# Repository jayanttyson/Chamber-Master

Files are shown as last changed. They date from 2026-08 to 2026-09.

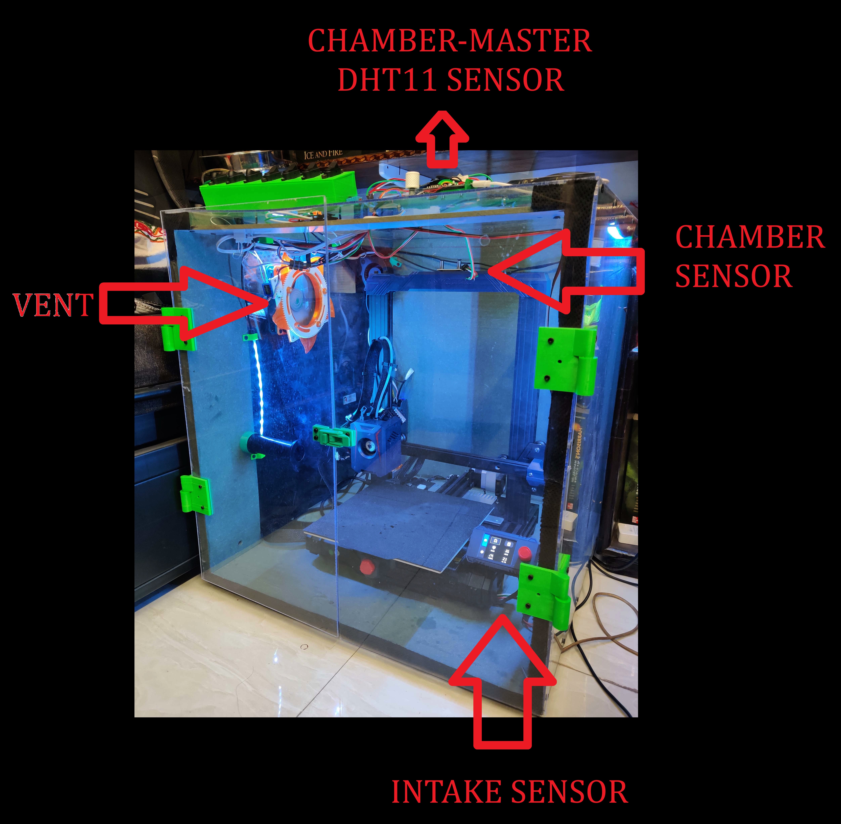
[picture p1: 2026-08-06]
Images/Setup.jpg

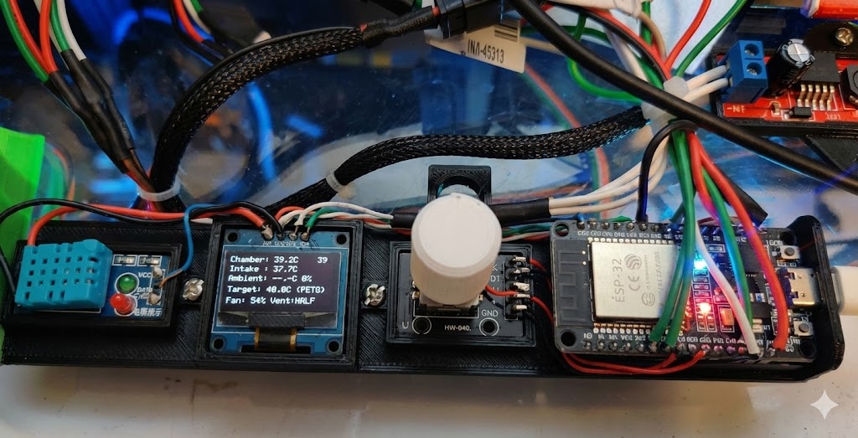
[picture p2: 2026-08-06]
Images/setup PCB.jpg

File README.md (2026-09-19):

<div align="center">

# **Chamber Master (v2.9-beta)**

**ESP32-based Smart 3D Printer Enclosure Controller**

Chamber Master Enclosure Setup

### 🎥 Watch the Video Demo
Watch the video (https://www.youtube.com/watch?v=ktXHP1pz5N8)

</div>

---

**Chamber Master** is an intelligent, ESP32-powered environmental controller for 3D printer enclosures. It features precise multi-zone temperature regulation, automated vent shutter control using directional hysteresis, dynamic 4-pin PC fan PWM control with low-side hard kill zero-RPM cut-off, adaptive material cooldown routines (for ABS/ASA thermal stress prevention), intake fault safety alerts, an OLED display UI, and a responsive Web Dashboard with mDNS support (`http://enclosure-monitor.local`).

---

## 🌟 Key Features

### 🌡️ Temperature Monitoring
temp
- **Chamber Temperature:** DS18B20 OneWire sensor placed inside the enclosure.
- **Intake Air Temperature:** Second DS18B20 placed on the printer's motherboard vent or fresh air intake path (essential for recirculation fault detection).
- **Ambient Environment:** DHT11 (or DHT22) for room temperature and relative humidity sensing.

### 🚪 Smart Vent Control
vent
- SG90 micro servo driving vent shutter with **three precise states**: Closed • Half-Open • Full-Open.
- Advanced **directional hysteresis logic** for rock-solid temperature stability (eliminates mechanical servo chatter and hunting).
- Servos perform an automated calibration cycle on boot for accurate homing.

### 💨 Fan Control & Hard Kill Transistor
- Standard 4-pin PC fan with 1 kHz PWM speed control and tachometer ISR feedback (real RPM displayed on OLED & web).
- Enforced **minimum 20% duty cycle (~51/255)** during active cooling and cooldown to prevent thermal shock.
- **2N2222 Low-Side Hard Kill Transistor:** Cuts the fan's Ground (GND) line on GPIO 15 when fan is OFF, overcoming the Intel 4-wire PC fan specification failsafe to achieve true 0 RPM.

### 🎯 Operating Modes
- **Material Presets:**
  - **PLA:** 30.0°C
  - **ASA:** 50.0°C
  - **ABS:** 60.0°C
  - **TPU:** 25.0°C
  - **PETG:** 40.0°C
- **Custom Mode:** User-selectable target (0.0°C to 120.0°C, 0.5°C step via encoder, debounced & saved persistently to NVS flash).
- **Adaptive Cooldown Mode:**
  - Starts at 20% fan speed + full vent open (vent opens before fan to avoid back-pressure noise).
  - Automatically adjusts fan speed to achieve ~1.5°C/min cooling rate.
  - Live progress bar + real-time countdown timer tick on OLED and Web Dashboard.

### 🛡️ Safety Features
- **Intake Fault Detection:** Triggers emergency max fan + full vent if intake air exceeds `Chamber Temp + 5.0°C` (prevents hot air recirculation into electronics).
- Automatic recovery banner clearing when fault condition resolves.

### 🖥️ User Interface (OLED & Encoder)
oled menu
- Crisp **SSD1306 128×64 OLED** display with blinking chamber temperature status.
- Intuitive **EC11 rotary encoder** with 50ms software debounced push button.
- **Double-Click** encoder button to safely exit active mode (closes vent, turns fan off).
- **QR Code Mode:** Generates pairing QR Code and text string for quick mobile access.

### 🌐 Responsive Web Dashboard
webpage gif
- Dark glassmorphic design with real-time 1-second background telemetry updates.
- Displays all sensor readings, fan speed/RPM, vent state, active mode & target temp.
- CSS animated spinning fan blades with dynamic RPM rotation speed.
- Cooldown progress ring + remaining time estimate.
- One-click **START COOLDOWN** remote button.
- Live printer camera iframe (`http://3d-print-live.local/`).
- Accessible on local network at **`http://enclosure-monitor.local`** (via mDNS).

---

## 📌 Hardware Pinout Diagram

| Hardware Module | ESP32 GPIO | Description |
| :--- | :--- | :--- |
| **SSD1306 OLED SDA** | GPIO 21 | I2C Data |
| **SSD1306 OLED SCL** | GPIO 22 | I2C Clock |
| **Chamber DS18B20** | GPIO 32 | OneWire Sensor Bus |
| **Intake DS18B20** | GPIO 13 | OneWire Sensor Bus |
| **Ambient DHT11** | GPIO 23 | Temperature & Humidity Data |
| **Fan PWM Signal** | GPIO 33 | 4-Pin Fan PWM Pin (1 kHz) |
| **Fan Tachometer** | GPIO 19 | Pulse ISR Input (Debounced) |
| **Hard Kill Transistor** | GPIO 15 | 2N2222 Base Pin (via 1kΩ Resistor) |
| **Vent Servo PWM** | GPIO 5 | SG90 Control Pulse |
| **Encoder CLK / DT / BTN**| GPIO 25 / 26 / 27 | Quadrature Encoder & Push Button |
| **Status LED** | GPIO 2 | High during active cooling/venting |

---

## 📁 Codebase Architecture

The project supports both single-file Arduino IDE workflows and PlatformIO multi-file modular builds:

- **Arduino IDE (Single-File / Tab Setup):**
  - **[`Chamber-Master.ino`](file:///c:/Users/JB/Documents/chamber%20master/Chamber-Master.ino):** Main standalone sketch containing full controller logic.
  - **[`config.h`](file:///c:/Users/JB/Documents/chamber%20master/config.h):** Separate tab for Wi-Fi credentials (`WIFI_SSID`, `WIFI_PASSWORD`, `MDNS_HOSTNAME`).

- **PlatformIO / VS Code (Modular Build):**
  - `include/`: Header declarations (`config.h`, `sensors.h`, `actuators.h`, `cooldown.h`, `ui_display.h`, `web_dashboard.h`).
  - `src/`: C++ module implementations (`main.cpp`, `config.cpp`, `sensors.cpp`, `actuators.cpp`, `cooldown.cpp`, `ui_display.cpp`, `web_dashboard.cpp`).

---

## 🖨️ Klipper Integration & Macros (v2.9-beta)

> *Hardware Tested & Verified: Klipper integration and macros proposed and verified on physical hardware by [Richard Kennett](https://github.com/richard-kennett) ([Issue #3](https://github.com/jayanttyson/Chamber-Master/issues/3#issuecomment-5619889047)).*

Chamber Master exposes a REST API endpoint (`/material`) allowing Klipper 3D printer firmware to automatically configure enclosure target temperatures and material profiles directly from filament start G-code or slicer profiles. Complete ready-to-use configuration files are located in the [`Klipper/`](Klipper/) directory.

### 1. Prerequisites on Klipper Host
Install mDNS resolution support on your Klipper host (Raspberry Pi / Linux):
```bash
sudo apt update && sudo apt install -y mdns avahi-daemon
```

### 2. Install Host Trigger Script
Copy [`Klipper/chamber_trigger.sh`](Klipper/chamber_trigger.sh) to your home directory (`$HOME`):
```bash
cp Klipper/chamber_trigger.sh ~/chamber_trigger.sh
chmod +x ~/chamber_trigger.sh
```
*Note: The script performs an IPv4 ping lookup (`ping -4 -c 1`) to cache and grab the controller's IP immediately, preventing curl DNS resolution timeouts in Klipper subshells.*

### 3. Klipper Macro Configuration
Add the tested macros below to your `printer.cfg` (or add `[include chamber_master.cfg]` using [`Klipper/chamber_master.cfg`](Klipper/chamber_master.cfg)):

```ini
[gcode_macro Chamber_Master]
description: Configuration variables for Chamber Master
variable_url: "enclosure-monitor.local"   # Matches mDNS hostname on OLED screen
gcode:

[gcode_shell_command chamber_curl]
command: bash $HOME/chamber_trigger.sh
timeout: 4.0
verbose: True

[gcode_macro SET_CHAMBER]
description: Set Chamber Master material mode and optional target temperature
gcode:
    {% set cf = printer.configfile.settings %}
    {% set url = cf['gcode_macro chamber_master'].variable_url %}

    # 1. Read material and force it to UPPERCASE
    {% set material = params.MATERIAL|default("XXX")|string|upper %}
    {% if material == "" %}
        {% set material = "XXX" %}
    {% endif %}

    # 2. Check if temperature was explicitly passed
    {% if 'TEMPERATURE' in params %}
        {% set temperature = params.TEMPERATURE|int %}
        RUN_SHELL_COMMAND CMD=chamber_curl PARAMS="{url} {material} {temperature}"
    {% else %}
        RUN_SHELL_COMMAND CMD=chamber_curl PARAMS="{url} {material}"
    {% endif %}

[gcode_macro START_CHAMBER_COOLDOWN]
description: Trigger Chamber Master adaptive cooldown routine
gcode:
    SET_CHAMBER MATERIAL=COOLDOWN
```

### 4. Slicer Filament Start G-Code Examples
In OrcaSlicer, PrusaSlicer, or Bambu Studio, add to your **Filament Start G-Code**:
```gcode
; Automate enclosure temperature for active filament
SET_CHAMBER MATERIAL=[filament_type]
```
For custom chamber temperatures:
```gcode
SET_CHAMBER MATERIAL=CUSTOM TEMPERATURE=55
```

### 5. Print End Cooldown
In your **Machine End G-Code** or `PRINT_END` macro:
```gcode
START_CHAMBER_COOLDOWN
```

---

## 🛠️ Setup & Installation

### Option A: Arduino IDE (Easiest)

1. **Add ESP32 Board Support:**
   - Go to **File → Preferences**
   - Add to *Additional Boards Manager URLs*: `https://raw.githubusercontent.com/espressif/arduino-esp32/gh-pages/package_esp32_index.json`
   - Go to **Tools → Board → Boards Manager**, search **esp32**, and click Install.

2. **Install Required Libraries (Tools → Manage Libraries):**
   - `Adafruit SSD1306`
   - `Adafruit GFX Library`
   - `OneWire`
   - `DallasTemperature`
   - `DHT sensor library` (by Adafruit)
   - `ESP32Encoder` (by Kevin Harrington)
   - `ESP32Servo` (by Kevin Harrington)
   - `QRCodeGFX` (by Ricmoo)

3. **Configure & Upload:**
   - Open [`Chamber-Master.ino`](file:///c:/Users/JB/Documents/chamber%20master/Chamber-Master.ino) in Arduino IDE.
   - Click the **`config.h`** tab at the top and set your Wi-Fi credentials:
     ```cpp
     #define WIFI_SSID     "YOUR_WIFI_NAME"
     #define WIFI_PASSWORD "YOUR_WIFI_PASSWORD"
     ```
   - Select Board **Tools → Board → ESP32 Dev Module**.
   - Connect your ESP32 and click **Upload**.

---

### Option B: PlatformIO (VS Code)

1. Open this workspace folder in VS Code with the PlatformIO extension installed.
2. Update Wi-Fi settings in `config.h`.
3. Connect your ESP32 via USB and run:
   ```bash
   pio run --target upload
   ```

---

## 💡 Pro Tips for Best Results

- **Intake Sensor Placement:** Place the intake DS18B20 directly at the fresh air entry point or near printer motherboard exhaust vents for early recirculation detection.
- **Fan Choice:** Choose a high-quality ≥2000 RPM 4-pin PWM fan (e.g., Noctua or Arctic) for silent yet effective airflow.
- **Vent Grease:** Apply a small amount of grease to gears and rotating flaps in the aperture vent mechanism for smooth operation.
- **Enclosure Material:** For ABS/ASA printing, pair with a well-sealed enclosure (IKEA Lack, Prusa enclosure, or custom build).

---

## 📄 License

MIT License. Free to use, modify, and distribute. Created by **Jayant Bhatia**.

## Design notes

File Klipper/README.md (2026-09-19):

# Chamber Master - Klipper Integration Guide

> **Hardware Tested & Verified**: Contributed by [Richard Kennett](https://github.com/richard-kennett) ([GitHub Issue #3](https://github.com/jayanttyson/Chamber-Master/issues/3#issuecomment-5619889047)).

This guide explains how to connect your **Chamber Master** enclosure controller to **Klipper 3D printer firmware**, allowing your slicer or filament profiles to automatically set enclosure modes and custom target temperatures, or trigger adaptive cooldown when a print finishes.

---

## Prerequisites

1. **mDNS Resolution on Klipper Host (Raspberry Pi / Linux):**
   Linux hosts often fail to resolve `.local` domains in subshells without mDNS packages installed. Run:
   ```bash
   sudo apt update
   sudo apt install -y mdns avahi-daemon
   ```

2. **Gcode Shell Command Extension:**
   Ensure `gcode_shell_command` is installed in Klipper (e.g. via **KIAUH** -> *Advanced* -> *G-Code Shell Command*).

---

## Installation Steps

### Step 1: Copy the Trigger Script
Copy [`chamber_trigger.sh`](chamber_trigger.sh) to your home directory (`$HOME`):
```bash
cp chamber_trigger.sh ~/chamber_trigger.sh
chmod +x ~/chamber_trigger.sh
```

> **Why this script is needed:**
> Linux curl subshells can hang or fail resolving `.local` mDNS domains. The script performs a fast IPv4 ping lookup (`ping -4 -c 1 enclosure-monitor.local`) to grab the IP address directly from the network cache before issuing the HTTP request to Chamber Master.

### Step 2: Include Configuration in Klipper
Copy [`chamber_master.cfg`](chamber_master.cfg) to your Klipper config directory (usually `~/printer_data/config/`):
```bash
cp chamber_master.cfg ~/printer_data/config/
```

Add the following line to your `printer.cfg`:
```ini
[include chamber_master.cfg]
```

Or copy the macros from [`chamber_master.cfg`](chamber_master.cfg) directly into your `printer.cfg`.

Restart Klipper (`FIRMWARE_RESTART`).

---

## Macros Reference

| Macro | Parameters | Example | Description |
| :--- | :--- | :--- | :--- |
| `SET_CHAMBER` | `MATERIAL` *(string)*, `TEMPERATURE` *(int/float, optional)* | `SET_CHAMBER MATERIAL=ABS` | Sets enclosure preset mode (`PLA`, `ASA`, `ABS`, `TPU`, `PETG`) |
| `SET_CHAMBER` | `MATERIAL=CUSTOM`, `TEMPERATURE=<target>` | `SET_CHAMBER MATERIAL=CUSTOM TEMPERATURE=55` | Sets custom target enclosure temperature |
| `SET_CHAMBER` | `MATERIAL=COOLDOWN` | `SET_CHAMBER MATERIAL=COOLDOWN` | Initiates active adaptive cooldown routine |
| `START_CHAMBER_COOLDOWN` | *(none)* | `START_CHAMBER_COOLDOWN` | Convenience alias for cooldown |

---

## Slicer Configuration

### Filament Start G-Code
In OrcaSlicer, PrusaSlicer, or Bambu Studio, add to your **Filament Start G-Code**:
```gcode
; Set Chamber Master mode based on active filament
SET_CHAMBER MATERIAL=[filament_type]
```
For filaments requiring a specific custom temperature:
```gcode
SET_CHAMBER MATERIAL=CUSTOM TEMPERATURE=55
```

### Machine End G-Code
In your slicer's **Machine End G-Code** or `PRINT_END` macro:
```gcode
; Start adaptive enclosure cooldown routine
START_CHAMBER_COOLDOWN
```

---

## Testing & Verification

You can test the trigger script directly in your terminal:
```bash
# Test material preset
bash ~/chamber_trigger.sh enclosure-monitor.local PETG

# Test custom temperature
bash ~/chamber_trigger.sh enclosure-monitor.local CUSTOM 60

# Test cooldown trigger
bash ~/chamber_trigger.sh enclosure-monitor.local COOLDOWN
```

Or from the Klipper console in Mainsail / Fluidd:
```gcode
SET_CHAMBER MATERIAL=PLA
SET_CHAMBER MATERIAL=CUSTOM TEMPERATURE=45
START_CHAMBER_COOLDOWN
```

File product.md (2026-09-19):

# Product Requirement & Specification Document (product.md)

## Project Overview
**Product Name:** Chamber Master (3D Printer Enclosure Controller)  
**Version:** 2.9-beta (Klipper Integration)  
**Author:** Jayant Bhatia  
**License:** MIT License  

The **3D Printer Enclosure Controller** is an intelligent, embedded ESP32 system designed for monitoring and controlling environmental conditions within a 3D printer enclosure. It provides real-time thermal monitoring across multiple zones, automated servo-driven ventilation control, dynamic 4-pin PC fan PWM management with low-side hard kill zero-RPM control, adaptive material cooldown routines (ABS/ASA thermal stress prevention), intake fault safety protection, rotary encoder UI with OLED display, a modern responsive web dashboard accessible via mDNS (`http://enclosure-monitor.local`), and native REST API integration with Klipper 3D printer firmware.

---

## Codebase Architecture (v2.5 Modular Structure)

The codebase supports **both** a clean multi-module architecture (PlatformIO / VS Code) and a single-file legacy format (`Chamber-Master.ino`):

```
chamber master/
├── Chamber-Master.ino      # Main standalone sketch (Arduino IDE)
├── config.h                # WiFi SSID, Password & Hostname configuration tab
├── README.md               # Hardware pinouts & setup guide
└── product.md              # Specification document
```

---

## Hardware Specifications & Pinout Mapping

| Component | Interface / Type | ESP32 GPIO Pin | Notes |
| :--- | :--- | :--- | :--- |
| **SSD1306 OLED (128x64)** | I2C (Address 0x3C) | SDA: GPIO 21, SCL: GPIO 22 | Main UI Display |
| **Chamber Temp Sensor** | DS18B20 (OneWire) | GPIO 32 | Internal enclosure temperature |
| **Intake Temp Sensor** | DS18B20 (OneWire) | GPIO 13 | Air intake temperature |
| **Ambient Temp & Humidity** | DHT11 | GPIO 23 | External ambient environment |
| **Fan PWM Control** | 4-Pin PWM Fan | GPIO 33 | 1 kHz, 8-bit resolution |
| **Fan Tachometer Input** | Pulse Frequency ISR | GPIO 19 | Measures fan RPM |
| **Fan Hard Kill Transistor** | 2N2222 Low-side switch | GPIO 15 | True 0 RPM ground cut-off (overrides CPU fan failsafe) |
| **Vent Servo Control** | SG90 / Continuous Servo | GPIO 5 | Microsecond pulse control |
| **Rotary Encoder CLK** | EC11 Encoder | GPIO 25 | Quadrature decoder |
| **Rotary Encoder DT** | EC11 Encoder | GPIO 26 | Quadrature decoder |
| **Rotary Encoder Button** | Push Button | GPIO 27 | Active LOW with internal pullup |
| **Status LED Indicator** | Onboard/External LED | GPIO 2 | High when fan & vent active |

---

## Operating Modes

1. **PLA Mode:** Target Chamber Temp = 30.0°C (Prevents heat creep & nozzle clogs).
2. **ASA Mode:** Target Chamber Temp = 50.0°C (Maintains chamber warmth for warping prevention).
3. **ABS Mode:** Target Chamber Temp = 60.0°C (High ambient heat retention for structural integrity).
4. **TPU Mode:** Target Chamber Temp = 25.0°C (Maximum active cooling for flexible filament).
5. **PETG Mode:** Target Chamber Temp = 40.0°C (Balanced thermal environment).
6. **CUSTOM Mode:** User selectable target (0.0°C to 120.0°C, 0.5°C step via encoder saved to NVS).
7. **COOLDOWN Mode:** Adaptive cooling routine. Starts at 20% fan duty (~51/255) to prevent thermal shock, adjusts fan duty dynamically based on temperature drop rate (°C/min), and closes vent upon completion. Progress tracked from original start temperature (v2.5 fix).
8. **QR CODE Mode:** Displays QR Code and URL string (`http://enclosure-monitor.local`) for quick mobile dashboard pairing.

---

## v2.5 Production Fixes

| # | Category | Fix |
| :--- | :--- | :--- |
| 1 | **Bug** | Cooldown progress bar now tracks from original start temp, not rolling 60s window |
| 2 | **Bug** | EC11 encoder button 50ms debounce eliminates phantom double-clicks |
| 3 | **Bug** | Button handler uses isolated timestamp (`btnNow`) preventing mid-loop timing drift |
| 4 | **Bug** | Cooldown start guards against NaN chamber temp (falls back to 60°C) |
| 5 | **Improvement** | NVS flash writes debounced to 2s idle on custom target encoder scrolling |
| 6 | **Improvement** | WiFi hostname changed from `"ENCLOSURE MONITOR"` to `"enclosure-monitor"` (RFC 952) |
| 7 | **Improvement** | `/status` endpoint includes `Access-Control-Allow-Origin: *` CORS header |
| 8 | **Improvement** | Unknown web routes return proper 404 via `server.onNotFound()` |
| 9 | **Improvement** | Vent opens before fan engages in cooldown to prevent back-pressure noise |
| 10 | **Cleanup** | Removed unnecessary `(int)` cast on `ambientHum` assignment (`roundf()` instead) |
| 11 | **Feature (v2.9-beta)** | REST API `/material` endpoint for Klipper 3D printer firmware & slicer integration (contributed / proposed by [@richard-kennett](https://github.com/richard-kennett)) |

---

## Hardware Rationale: 4-Pin CPU Fan Failsafe & Hard Kill Transistor

Standard 4-pin PC cooling fans adhere to the **Intel 4-Wire PWM Fan Specification**. As a hardware CPU protection feature:
- Many PC fans treat a **0% PWM signal** or disconnected PWM wire as an emergency state, keeping the fan spinning at a **minimum fallback speed (~20% RPM, ~500–800 RPM)** so a CPU does not overheat if the PWM controller fails.
- Therefore, driving 0% duty on GPIO 33 alone fails to turn off the fan on hardware-failsafe PC fans.
- The **2N2222 low-side transistor** circuit on GPIO 15 physically cuts the fan's Ground (GND) rail when `FAN_OFF` is commanded, guaranteeing **true 0 RPM operation** and eliminating lingering motor hum/spin.

---

## Control Logic & State Management

### 1. Vent Servo Control
- **Closed:** Continuous pulse = 2000 µs (SERVO_FORWARD_PULSE).
- **Open:** Continuous pulse = 1000 µs (SERVO_REVERSE_PULSE).
- **Stop:** Pulse = 1500 µs (SERVO_STOP_PULSE).
- **Hysteresis Logic:**
  - `Temp > Target + 2.0°C`: Full Open Vent + FAN_HIGH (100% duty).
  - `Temp > Target - 1.0°C`: Half Open Vent + FAN_LOW (55% duty).
  - `Temp < Target - 2.0°C`: Close Vent + FAN_OFF (0% duty, Hard Kill active).

### 2. Fan & Hard Kill Transistor Operation
- **FAN_OFF / 0 Duty:** GPIO 15 goes `LOW`, turning off the 2N2222 transistor to disconnect the fan GND rail. `fanPWM.writeScaled(0.0f)` sets PWM to 0.
- **FAN_LOW / FAN_HIGH / Active Cooldown:** GPIO 15 goes `HIGH`, connecting fan GND rail. PWM duty cycle regulates fan speed.

### 3. Intake Fault Protection
- If `Intake Temp > Chamber Temp + 5.0°C`, system triggers `INTAKE FAULT`.
- Vent immediately opens fully, fan runs at `FAN_HIGH` (100%), OLED shows `INTAKE FAULT!`, and Web Dashboard displays a blinking alert banner.
- Clears automatically when `Intake Temp <= Chamber Temp + 2.0°C`.

---

## Web Dashboard & REST API Specs

- **GET `/`**: Responsive HTML/CSS Web Dashboard with glassmorphism design, real-time stat cards, spinning fan SVG animation, circular cooldown progress gauge, live camera iframe embed (`http://3d-print-live.local/`), and start cooldown button.
- **GET `/status`**: Returns JSON object:
  ```json
  {
    "chamberTemp": 42.5,
    "intakeTemp": 31.0,
    "ambientTemp": 24.2,
    "ambientHum": 45,
    "fanRpm": 2100,
    "fanDuty": 55,
    "activeMode": "ABS",
    "targetTemp": "60.0",
    "ventState": "HALF OPEN",
    "fault": "NONE",
    "estSeconds": -1,
    "progress": 0.0
  }
  ```
- **POST `/start_cooldown`**: Initiates adaptive cooldown mode from web interface.
- **GET / POST `/material`**: Sets active material preset mode or custom temperature from Klipper / slicer macros.
  - **Parameters:**
    - `material` *(string, required)*: Material mode name (`PLA`, `ASA`, `ABS`, `TPU`, `PETG`, `CUSTOM`, `COOLDOWN`). Case-insensitive.
    - `temperature` or `temp` *(float, optional)*: Target chamber temperature in °C (0.0 to 120.0). Applied and saved to NVS when `material=CUSTOM`.
  - **Success Response (200 OK):**
    ```json
    {
      "status": "OK",
      "mode": "PLA",
      "targetTemp": 30.0
    }
    ```
  - **Error Response (400 Bad Request):**
    ```json
    {
      "error": "Missing 'material' parameter"
    }
    ```

---

## Klipper Integration Architecture (v2.9-beta)

> **Physical Hardware Validation:** Verified and contributed by [Richard Kennett](https://github.com/richard-kennett) ([Issue #3](https://github.com/jayanttyson/Chamber-Master/issues/3#issuecomment-5619889047)).

1. **Host Prerequisites:**
   - Linux Klipper host requires mDNS name resolution installed (`sudo apt install -y mdns avahi-daemon`).
2. **Fast IPv4 Resolution Script (`chamber_trigger.sh`):**
   - Resolves `enclosure-monitor.local` via `ping -4 -c 1 ${URL}` to populate and read the local IP directly, preventing curl DNS resolution timeouts in Klipper subshells.
   - Dispatches curl call to `/material` endpoint with material and optional temperature parameters.
3. **Klipper Macros (`chamber_master.cfg`):**
   - `[gcode_macro Chamber_Master]`: Stores `variable_url: "enclosure-monitor.local"`.
   - `[gcode_shell_command chamber_curl]`: Invokes `bash $HOME/chamber_trigger.sh` with a 4.0s timeout.
   - `[gcode_macro SET_CHAMBER]`: Normalizes material to uppercase and passes target temperature if specified.
   - `[gcode_macro START_CHAMBER_COOLDOWN]`: Dispatches `SET_CHAMBER MATERIAL=COOLDOWN` for automated post-print cooling.

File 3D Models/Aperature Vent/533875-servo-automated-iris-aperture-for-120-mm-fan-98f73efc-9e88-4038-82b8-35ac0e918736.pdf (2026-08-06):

## Summary

Remix for fitting the iris mechanism directly to 120 mm fan.

3D Printers (https://printables.com/model?categoryId=1) > 3D Printers - Upgrades (https://printables.com/model?categoryId=2)

This is a remix from https://www.printables.com/model/5122-servoautomated-iris-aperture-for-air-flow-control (https://www.printables.com/model/5122-servo-automated-iris-aperture-for-air-flow-control)
Many thanks to @AcEKrystal

I've changed the base plate only, to mount it directly to 120 mm fan. Servo motor is moved to allow 4 screws for tightening to the fan.

Only “baseplate-aperature-120mm-fan” file was modified, rest of the files are original, but I've included them here to have complete set of files to make this project.

Design has two things improved that are not visible on the pictures:
1. Servo 3 mm screw hole is moved slightly because it was at an angle
2. Right side of the servo mounting plate is extended so that the blade is not catching on the edge, but rather is gliding on the mount itself.

## This remix is based on

M (https://printables.com/@MichalCiombor_108701) MichalCiombor (https://printables.com/@MichalCiombor_108701)

## Servo automated iris / aperture for 120 mm fan

VIEW IN BROWSER (https://printables.com/model/533875-servo-automated-iris-aperture-for-120-mm-fan)

updated 23. 7. 2023 | published 23. 7. 2023

3D MODEL ONLY

## Model files

Servo automated iris / aperture for air flow controll (https://printables.com/model/5122-servo-automated-iris-aperture-for-air-flow-control)

by AcE Krystal (https://printables.com/@AcEKrystal)

## License

This work is licensed under a
Creative Commons (4.0 International License)

Attribution-ShareAlike (http://creativecommons.org/licenses/by-sa/4.0/)

✖ | Sharing without ATTRIBUTION
✔ | Remix Culture allowed
✔ | Commercial Use
✔ | Free Cultural Works
✔ | Meets Open Definition

baseplate-aperature-120mm-fan.stl

door_blade_final.stl

spur-gear-12th-125mo-145at.stl

spur-gear-107th-125mo-145at.stl

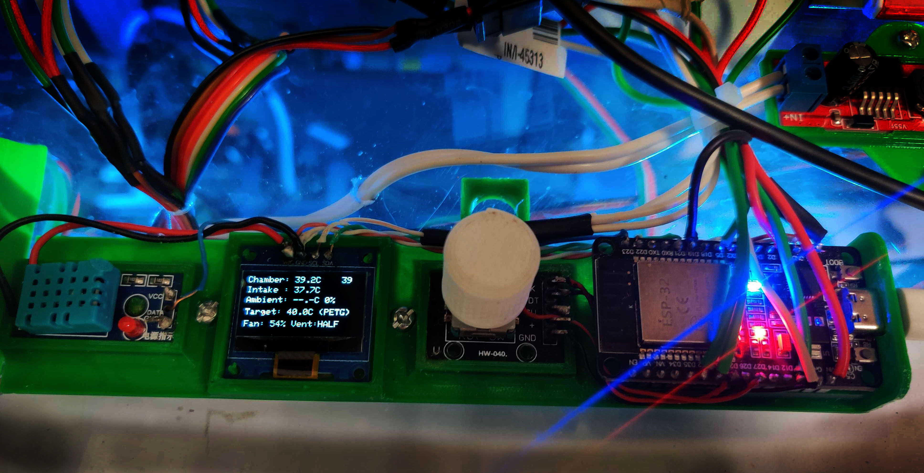
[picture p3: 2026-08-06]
Images/chamber master.jpg

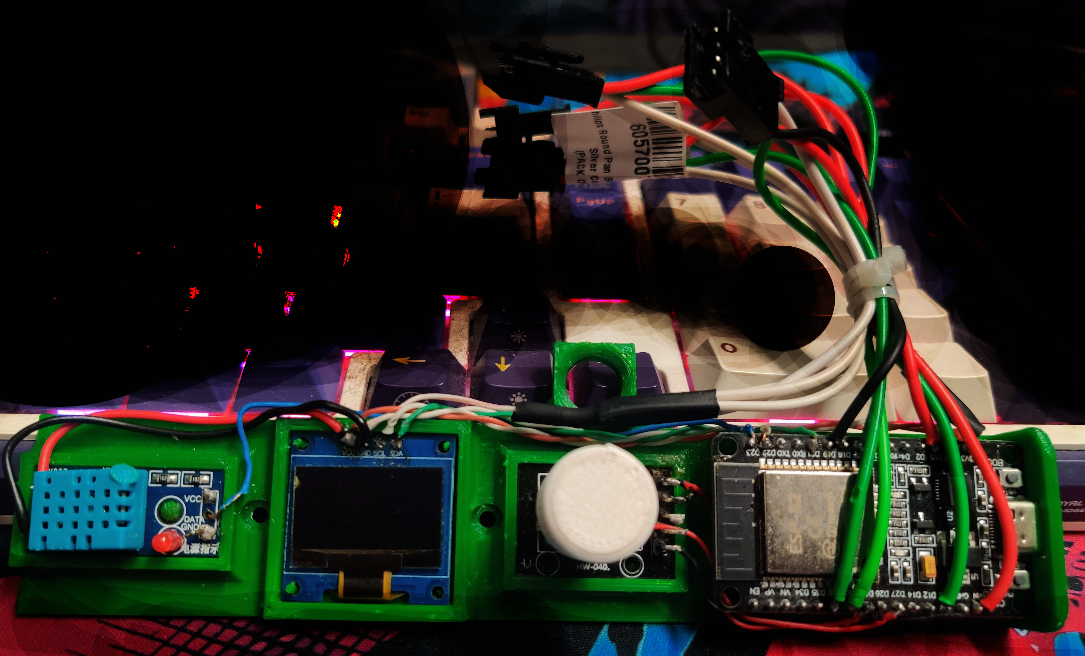
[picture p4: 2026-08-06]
Images/pcb off.jpg

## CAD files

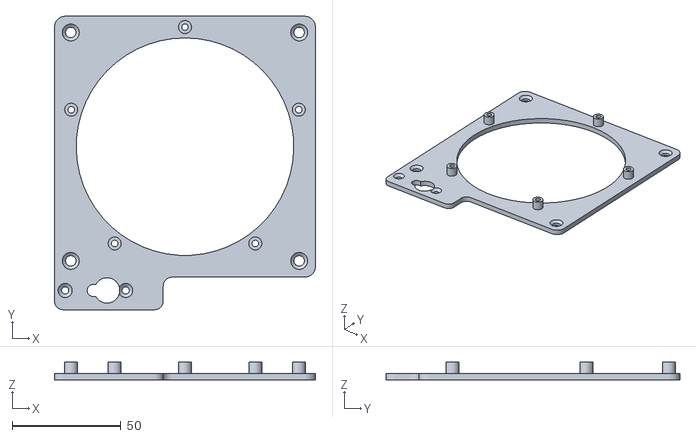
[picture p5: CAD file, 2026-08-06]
3D Models/Aperature Vent/baseplate-aperature-120mm-fan.stl
120.0 x 135.0 x 8.20

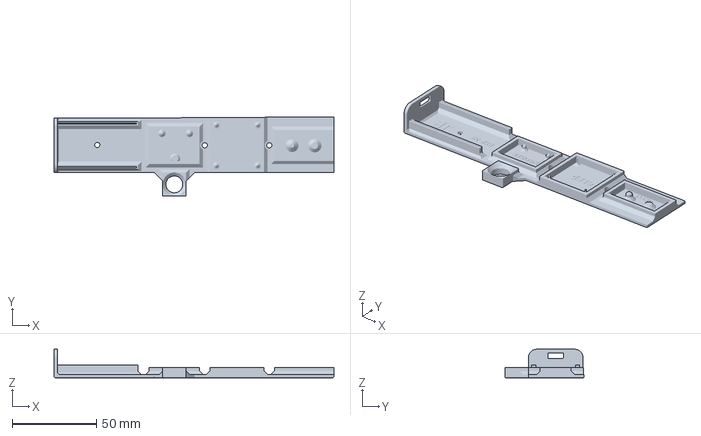
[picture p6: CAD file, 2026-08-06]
3D Models/Chamber-Master mount/pcb mounts_1.3mf
166.6 x 47.2 x 17.0 mm

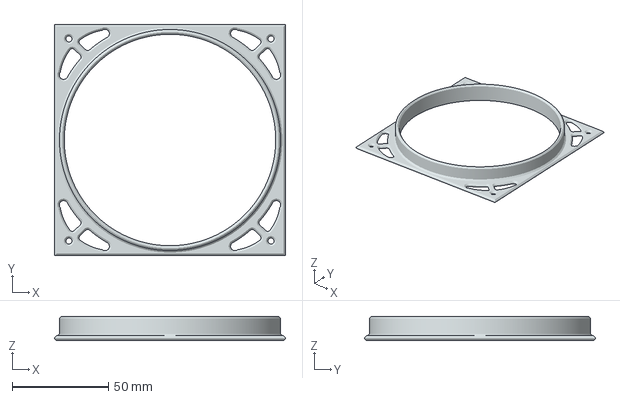
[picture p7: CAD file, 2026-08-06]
3D Models/MISC/fan bracket male.3mf
120.0 x 120.0 x 12.5 mm

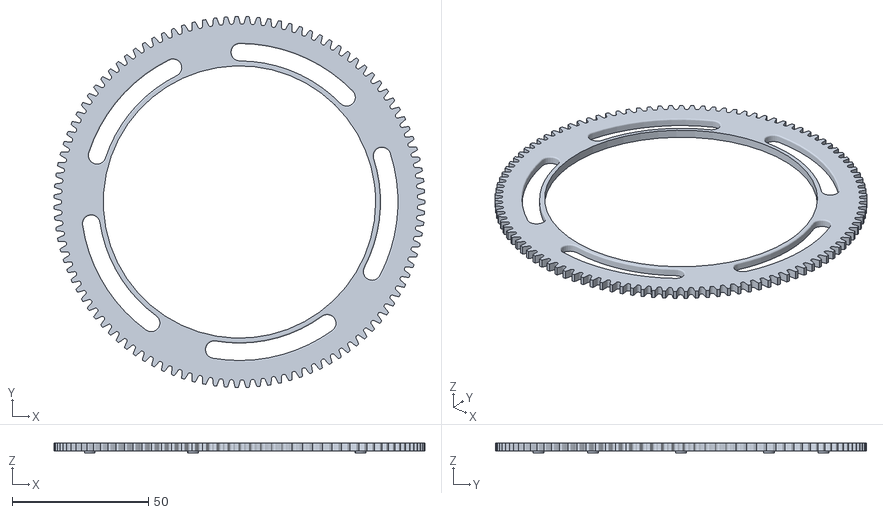
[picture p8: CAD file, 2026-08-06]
3D Models/Aperature Vent/spur-gear-107th-125mo-145at.stl
136.2 x 136.2 x 3.80

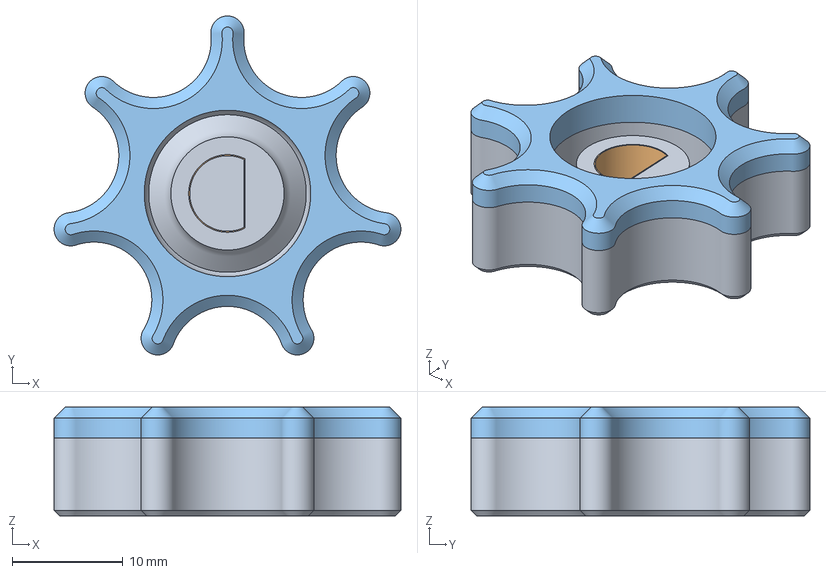
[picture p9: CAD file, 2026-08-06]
3D Models/MISC/Dshaft 6mm knob.3mf
31.3 x 30.6 x 9.80 mm

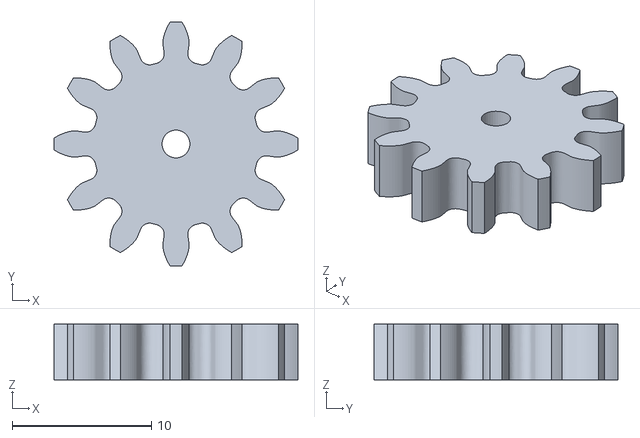
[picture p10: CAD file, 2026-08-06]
3D Models/Aperature Vent/spur-gear-12th-125mo-145at.stl
17.5 x 17.5 x 4.00

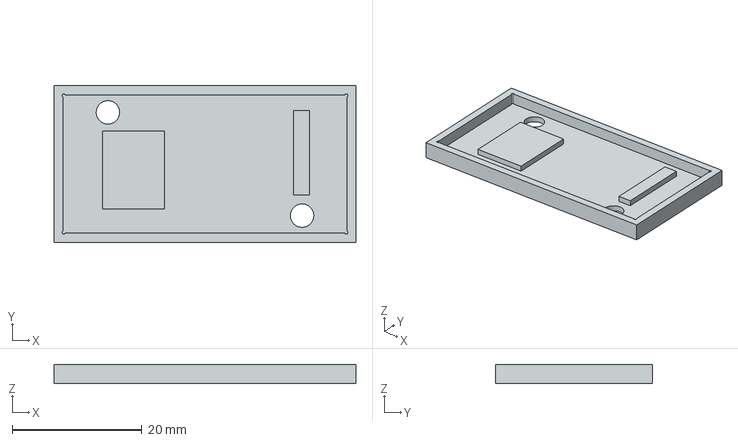
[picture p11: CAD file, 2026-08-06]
3D Models/MISC/XM4015E1.3mf
46.5 x 24.1 x 3.00 mm

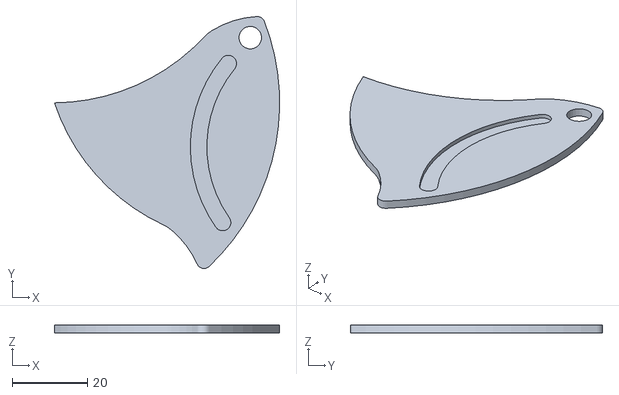
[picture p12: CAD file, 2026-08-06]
3D Models/Aperature Vent/door_blade_final.stl
60.0 x 67.1 x 2.00

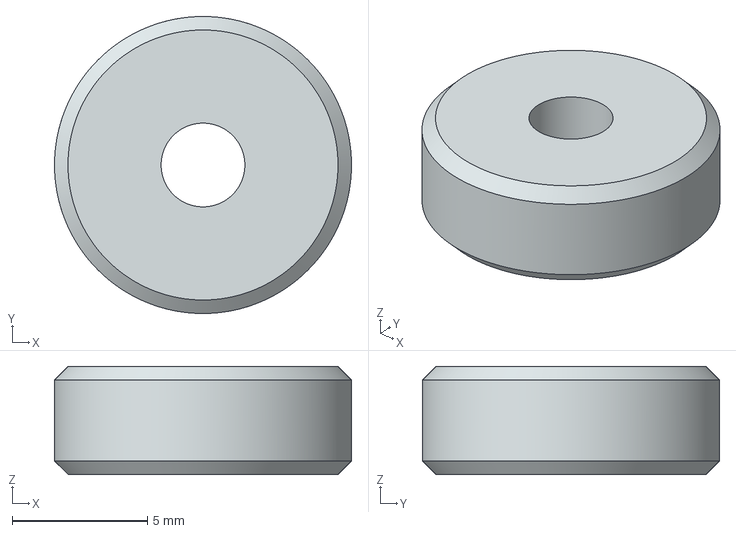
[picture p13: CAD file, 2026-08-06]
3D Models/MISC/simple 3mm screw washer_2.3mf
11.0 x 11.0 x 4.00 mm

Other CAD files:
3D Models/Chamber-Master mount/chambertemp mount.prt
3D Models/Chamber-Master mount/pcb mounts.prt
3D Models/MISC/Dshaft 6mm knob.prt
3D Models/MISC/XM4015E1 footprint.prt
3D Models/MISC/esp 32 usb C 30 pin Footprint.prt
3D Models/MISC/fan bracket male.prt

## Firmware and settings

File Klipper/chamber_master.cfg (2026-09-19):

# ==============================================================================
# Chamber Master - Klipper Configuration & Macros
# Tested and contributed by Richard Kennett (https://github.com/richard-kennett - Issue #3)
#
# Requirements:
#   1. gcode_shell_command extension enabled in Klipper (installed via KIAUH)
#   2. chamber_trigger.sh placed at $HOME/chamber_trigger.sh:
#        cp Klipper/chamber_trigger.sh ~/chamber_trigger.sh
#        chmod +x ~/chamber_trigger.sh
#   3. mDNS resolution package on Klipper host:
#        sudo apt update && sudo apt install -y mdns
#
# Installation:
#   Include this file in your printer.cfg:
#     [include chamber_master.cfg]
# ==============================================================================

[gcode_macro Chamber_Master]
description: Configuration variables for Chamber Master
variable_url: "enclosure-monitor.local"   # Matches hostname on OLED screen
gcode:
    # Configuration storage macro

[gcode_shell_command chamber_curl]
command: bash $HOME/chamber_trigger.sh
timeout: 4.0
verbose: True

[gcode_macro SET_CHAMBER]
description: Set Chamber Master material mode (PLA, ASA, ABS, TPU, PETG, CUSTOM, COOLDOWN) and optional target temperature
gcode:
    {% set cf = printer.configfile.settings %}
    {% set url = cf['gcode_macro chamber_master'].variable_url %}

    # 1. Read material and force to UPPERCASE
    {% set material = params.MATERIAL|default("XXX")|string|upper %}
    {% if material == "" %}
        {% set material = "XXX" %}
    {% endif %}

    # 2. Check if temperature was explicitly passed
    {% if 'TEMPERATURE' in params %}
        {% set temperature = params.TEMPERATURE|int %}
        RUN_SHELL_COMMAND CMD=chamber_curl PARAMS="{url} {material} {temperature}"
    {% else %}
        RUN_SHELL_COMMAND CMD=chamber_curl PARAMS="{url} {material}"
    {% endif %}

[gcode_macro SET_CHAMBER_MATERIAL]
description: Alias for SET_CHAMBER (backwards compatibility)
gcode:
    {% if 'TEMPERATURE' in params %}
        SET_CHAMBER MATERIAL={params.MATERIAL} TEMPERATURE={params.TEMPERATURE}
    {% else %}
        SET_CHAMBER MATERIAL={params.MATERIAL}
    {% endif %}

[gcode_macro START_CHAMBER_COOLDOWN]
description: Trigger Chamber Master adaptive enclosure cooldown routine
gcode:
    SET_CHAMBER MATERIAL=COOLDOWN

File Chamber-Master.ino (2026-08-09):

/*
 * Chamber Master - 3D Printer Enclosure Controller - Version 2.8 (Single File Production Sketch)
 * 
 * Hardware Rationale (Why Hard Kill Transistor is Needed):
 * Standard 4-pin PC cooling fans adhere to the Intel 4-Wire PWM Fan Specification.
 * As an integrated CPU safety feature, many PC fans refuse to stop when PWM duty
 * is set to 0% (falling back to a default ~20% min RPM curve so CPUs do not overheat
 * if PWM control fails). The 2N2222 low-side transistor on GPIO 15 physically cuts 
 * the fan's Ground (GND) line when FAN_OFF is commanded, ensuring true 0 RPM operation.
 * 
 * Major Version 2.8 Fixes & Features:
 * 1. HIGH-Level Voltage Matching on FAN_OFF (Compatible with inline diodes):
 *    - On FAN_OFF, GPIO 33 is now driven HIGH (3.3V). Standard 4-pin fans have an internal
 *      pull-up to 3.3V/5V on the PWM line. Driving GPIO 33 HIGH eliminates the voltage
 *      potential difference (3.3V - 3.3V = 0V) across the wire and inline diodes (e.g., 1N5408G).
 *      Zero voltage potential prevents forward diode conduction and parasitic ground leakage,
 *      stopping the fan 100% DEAD (true 0 RPM) regardless of heat-shrunk diodes or fan wiring.
 * 2. Automatic Re-Attachment:
 *    - On FAN_ON, the 25 kHz PWM timer and Tachometer interrupt are automatically re-attached,
 *      restoring full 0-100% PWM speed control and RPM sensing seamlessly.
 * 
 * Author: Jayant Bhatia
 * Version: 2.8
 * Date: August 2026
 * License: MIT License
 */

#define DEBUG // Comment this line to disable Serial debug output

#include <Arduino.h>
#include <Wire.h>
#include <Adafruit_GFX.h>
#include <Adafruit_SSD1306.h>
#include <OneWire.h>
#include <DallasTemperature.h>
#include <DHT.h>
#include <ESP32Encoder.h>
#include <ESP32Servo.h>
#include <ESP32PWM.h>
#include <WiFi.h>
#include <WebServer.h>
#include <Preferences.h>
#include <QRCodeGFX.h>
#include <ESPmDNS.h>

#include "config.h"

// ==================== HARD KILL FOR TRUE 0 RPM ====================
// Low-side 2N2222 transistor cuts fan GND rail to override CPU fan 20% failsafe
#define FAN_POWER_PIN 15
// ==================================================================

// ==================== PIN ASSIGNMENTS ====================
#define SCREEN_WIDTH 128
#define SCREEN_HEIGHT 64
#define OLED_RESET    -1
Adafruit_SSD1306 display(SCREEN_WIDTH, SCREEN_HEIGHT, &Wire, OLED_RESET);

#define CHAMBER_PIN   32
#define INTAKE_PIN    13
#define DHT_PIN       23
#define DHTTYPE       DHT11

#define FAN_PIN       33
#define FAN_TACH_PIN  19
#define SERVO_PIN     5

#define ENCODER_CLK   25
#define ENCODER_DT    26
#define ENCODER_BTN   27

#define LED_PIN       2
// ========================================================

// ==================== FAN PWM CONFIGURATION ====================
const int FAN_PWM_FREQ = 25000; // 25 kHz - Official Intel 4-Wire PWM Fan Spec
const int FAN_PWM_RES  = 8;
volatile uint8_t fanDutyCycle = 0;
ESP32PWM fanPWM;

const uint8_t NORMAL_MIN_DUTY = 51;  // ~20% - enforced in normal modes & adaptive cooldown
// ==============================================================

// ==================== RPM MEASUREMENT ====================
volatile unsigned long fanPulseCount = 0;
volatile unsigned long lastFanPulseUs = 0;
unsigned long lastRpmMs = 0;
const unsigned long RPM_SAMPLE_MS = 1000;
float currentFanRPM = 0.0;
// =========================================================

// ==================== TEMPERATURE SENSORS ====================
OneWire oneWireChamber(CHAMBER_PIN);
DallasTemperature chamberSensor(&oneWireChamber);
OneWire oneWireIntake(INTAKE_PIN);
DallasTemperature intakeSensor(&oneWireIntake);
DHT dht(DHT_PIN, DHTTYPE);
// ===========================================================

// ==================== ROTARY ENCODER ====================
ESP32Encoder encoder;
long lastEncoderCount = 0;
// ========================================================

// ==================== MENU SYSTEM ====================
const char *menuItems[] = {"PLA", "ASA", "ABS", "TPU", "PETG", "CUSTOM", "COOLDOWN", "QR CODE"};
const float menuTargets[] = {30.0, 50.0, 60.0, 25.0, 40.0, -1.0, -2.0, -3.0};
const int MENU_LEN = 8;

int menuIndex = 0;
bool inSubMenu = false;
int activeMode = 0;
float customTarget = 30.0;
float activeTarget = 30.0;
// ====================================================

// ==================== PERSISTENT SETTINGS ====================
Preferences prefs;
// ===========================================================

// ==================== DISPLAY UPDATE ====================
unsigned long lastOledMs = 0;
const unsigned long OLED_INTERVAL_MS = 200;

unsigned long lastTempRequestMs = 0;
const unsigned long DS_CONV_MS = 750;
bool tempsRequested = false;

unsigned long lastDhtReadMs = 0;
const unsigned long DHT_MIN_INTERVAL_MS = 3500;

float chamberTemp = NAN;
float intakeTemp = NAN;
float ambientTemp = NAN;
float ambientHum = NAN;

bool displayNeedsUpdate = true;
// ====================================================

// ==================== VENT SERVO CONTROL ====================
Servo ventServo;
enum VentState {VENT_CLOSED, VENT_HALF_OPENING, VENT_HALF_OPEN, VENT_OPENING, VENT_OPEN, VENT_CLOSING};
VentState ventState = VENT_CLOSED;
unsigned long ventActionStartMs = 0;

const unsigned long SERVO_OPEN_TIME = 850;
const unsigned long SERVO_HALF_OPEN_TIME = 425;
const unsigned long SERVO_CLOSE_TIME = 1100;
const unsigned long SERVO_FULL_TO_HALF_TIME = 750;

const int SERVO_STOP_PULSE = 1500;
const int SERVO_FORWARD_PULSE = 2000;  // Close vent
const int SERVO_REVERSE_PULSE = 1000;  // Open vent
// ===========================================================

// ==================== FAN STATE CONTROL ====================
enum FanSpeed {FAN_OFF, FAN_LOW, FAN_HIGH};
FanSpeed fanSpeed = FAN_OFF;
bool ledOn = false;

// Directional hysteresis thresholds (offsets from activeTarget in °C)
// Fan ONLY engages when chamber temp EXCEEDS target, never below.
// Dead-band widths: HALF = 1.5°C, FULL = 1.0°C (prevents servo chatter)
const float HYSTERESIS_TO_HALF   =  1.0f;  // CLOSED → HALF when chamberTemp > target + 1.0°C
const float HYSTERESIS_TO_CLOSED = -0.5f;  // HALF → CLOSED when chamberTemp < target - 0.5°C
const float HYSTERESIS_TO_FULL   =  3.0f;  // HALF → FULL when chamberTemp > target + 3.0°C
const float HYSTERESIS_FROM_FULL =  2.0f;  // FULL → HALF when chamberTemp <= target + 2.0°C
// ===========================================================

// ==================== UI ELEMENTS ====================
bool chamberTempVisible = true;
unsigned long lastBlinkMs = 0;
const unsigned long BLINK_INTERVAL_MS = 500;

unsigned long lastBtnPressMs = 0;
const unsigned long DOUBLE_CLICK_MS = 250;
bool waitingForSecondSHOW = false;
unsigned long lastBtnDebounceMs = 0;
const unsigned long BTN_DEBOUNCE_MS = 50;

unsigned long lastCustomChangeMs = 0;
bool customTargetDirty = false;
// ====================================================

// ==================== WIFI SETTINGS ====================
const char *ssid = WIFI_SSID;
const char *password = WIFI_PASSWORD;
WebServer server(80);
// ======================================================

// ==================== COOLDOWN LOGIC ====================
float cooldownStartTemp = 0.0;
float cooldownLastTemp = 0.0;
unsigned long cooldownLastCheckMs = 0;
uint8_t cooldownFanDuty = NORMAL_MIN_DUTY;

const float COOLDOWN_RATE_DEG_PER_MIN = 1.5;
const float COOLDOWN_TARGET_OFFSET = 3.0;
const unsigned long COOLDOWN_SAMPLE_MS = 60000;

unsigned long cooldownStartMs = 0;
long cooldownEstSeconds = -1;
float cooldownProgress = 0.0;
unsigned long lastCountdownSecMs = 0;
// =====================================================

// ==================== SAFETY FEATURES ====================
bool intakeFault = false;
// ========================================================

// ==================== QR CODE DISPLAY ====================
QRCodeGFX qrcode(display);
// ========================================================

// ==================== STARTUP VENT CALIBRATION ====================
enum StartupVentState {VENT_START_CLOSING, VENT_START_WAIT_CLOSED, VENT_START_OPENING, VENT_START_WAIT_OPEN, VENT_START_CLOSING_AGAIN, VENT_START_WAIT_CLOSED_AGAIN, VENT_START_DONE};
StartupVentState startupVentState = VENT_START_CLOSING;
unsigned long startupVentTimer = 0;
bool startupVentDone = false;
// ================================================================

// ==================== FAN TACH INTERRUPT WITH DEBOUNCING ====================
void IRAM_ATTR fanPulseISR() {
  unsigned long nowUs = micros();
  // Debounce threshold: 2000 µs minimum pulse interval (max 15,000 RPM)
  if (nowUs - lastFanPulseUs >= 2000) {
    fanPulseCount++;
    lastFanPulseUs = nowUs;
  }
}
// ===========================================================================

// ==================== OLED INITIALIZATION ====================
void ensureOLED() {
  if (!display.begin(SSD1306_SWITCHCAPVCC, 0x3C)) {
    #ifdef DEBUG
    Serial.println(F("SSD1306 allocation failed"));
    #endif
    for (;;) delay(1000);
  }
  display.clearDisplay();
  display.display();
}
// ===========================================================

// ==================== BLINKING CHAMBER TEMP ====================
void drawChamberTempBlink() {
  if (millis() - lastBlinkMs >= BLINK_INTERVAL_MS) {
    lastBlinkMs = millis();
    chamberTempVisible = !chamberTempVisible;
    displayNeedsUpdate = true;
  }
  display.setTextSize(1);
  display.setTextColor(chamberTempVisible ? SSD1306_WHITE : SSD1306_BLACK);
  display.setCursor(108, 0);
  display.printf("%02d", isnan(chamberTemp) ? 0 : (int)round(chamberTemp));
}
// ===========================================================

// ==================== MAIN MENU DISPLAY ====================
void drawMainMenu() {
  display.clearDisplay();
  display.setTextColor(SSD1306_WHITE);
  int16_t x1, y1;
  uint16_t w, h;

  if (menuIndex == 6) {
    display.setTextSize(2);
    display.getTextBounds("COOLDOWN", 0, 0, &x1, &y1, &w, &h);
    display.setCursor((SCREEN_WIDTH - w) / 2, (SCREEN_HEIGHT - h) / 2);
    display.print("COOLDOWN");
  } else if (menuIndex == 7) {
    if (WiFi.status() == WL_CONNECTED) {
      String url = "http://enclosure-monitor.local";
      qrcode.setScale(2);
      qrcode.draw(url.c_str(), 46, 8);
      const char* txt = "enclosure-monitor.local";
      display.setTextSize(1);
      display.getTextBounds(txt, 0, 0, &x1, &y1, &w, &h);
      display.setCursor((SCREEN_WIDTH - w) / 2, 2);
      display.print(txt);
    } else {
      display.setTextSize(1);
      display.getTextBounds("WiFi Disconnected", 0, 0, &x1, &y1, &w, &h);
      display.setCursor((SCREEN_WIDTH - w) / 2, 28);
      display.print("WiFi Disconnected");
    }
  } else {
    display.setTextSize(3);
    display.getTextBounds(menuItems[menuIndex], 0, 0, &x1, &y1, &w, &h);
    display.setCursor((SCREEN_WIDTH - w) / 2, (SCREEN_HEIGHT - h) / 2);
    display.print(menuItems[menuIndex]);
    display.setTextSize(1);
    display.setCursor((SCREEN_WIDTH - 80) / 2, (SCREEN_HEIGHT - h) / 2 + h + 6);
    display.printf("Target: %.1fC", menuTargets[menuIndex] == -1.0 ? customTarget : menuTargets[menuIndex]);
  }
  drawChamberTempBlink();
  display.display();
  displayNeedsUpdate = false;
}
// ===========================================================

// ==================== COOLDOWN SCREEN ====================
void drawCooldownScreen() {
  display.clearDisplay();
  display.setTextSize(1);
  display.setTextColor(SSD1306_WHITE);
  display.setCursor(20, 0);
  display.print("COOLING DOWN");
  display.setCursor(0, 12);
  display.printf("Fan: %3d%% (RPM: %4d)", (fanDutyCycle * 100) / 255, (int)currentFanRPM);

  display.setCursor(0, 24);
  display.print("Time: ");
  if (cooldownEstSeconds == 0) {
    display.print("Cooled");
  } else if (cooldownEstSeconds < 0) {
    display.print("Calculating...");
  } else if (cooldownEstSeconds >= 3600) {
    display.printf("%dh", cooldownEstSeconds / 3600);
  } else if (cooldownEstSeconds >= 120) {
    display.printf("%dm", cooldownEstSeconds / 60);
  } else {
    int mins = cooldownEstSeconds / 60;
    int secs = cooldownEstSeconds % 60;
    display.printf("%dm%02ds", mins, secs);
  }

  display.setCursor(0, 36);
  display.printf("Amb: %sC %d%%", isnan(ambientTemp) ? "--.-" : String(ambientTemp, 1).c_str(), isnan(ambientHum) ? 0 : (int)ambientHum);

  int barY = 56, barWidth = 120, barHeight = 6;
  display.drawRect(3, barY, barWidth, barHeight, SSD1306_WHITE);
  int fill = (int)(cooldownProgress * (barWidth - 2));
  if (fill > 0) display.fillRect(4, barY + 1, fill, barHeight - 2, SSD1306_WHITE);

  drawChamberTempBlink();
  display.display();
  displayNeedsUpdate = false;
}
// ========================================================
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
void loop() {
  // Always service web client requests even during startup calibration
  if (WiFi.status() == WL_CONNECTED) {
    server.handleClient();
  }

  if (!startupVentDone) {
    unsigned long now = millis();
    switch (startupVentState) {
      case VENT_START_CLOSING: if (now - startupVentTimer >= SERVO_CLOSE_TIME) { ventServo.writeMicroseconds(SERVO_STOP_PULSE); startupVentState = VENT_START_WAIT_CLOSED; startupVentTimer = now; } break;
      case VENT_START_WAIT_CLOSED: if (now - startupVentTimer >= 1000) { ventServo.writeMicroseconds(SERVO_REVERSE_PULSE); startupVentState = VENT_START_OPENING; startupVentTimer = now; } break;
      case VENT_START_OPENING: if (now - startupVentTimer >= SERVO_OPEN_TIME) { ventServo.writeMicroseconds(SERVO_STOP_PULSE); startupVentState = VENT_START_WAIT_OPEN; startupVentTimer = now; } break;
      case VENT_START_WAIT_OPEN: if (now - startupVentTimer >= 1000) { ventServo.writeMicroseconds(SERVO_FORWARD_PULSE); startupVentState = VENT_START_CLOSING_AGAIN; startupVentTimer = now; } break;
      case VENT_START_CLOSING_AGAIN: if (now - startupVentTimer >= SERVO_CLOSE_TIME) { ventServo.writeMicroseconds(SERVO_STOP_PULSE); startupVentState = VENT_START_WAIT_CLOSED_AGAIN; startupVentTimer = now; } break;
      case VENT_START_WAIT_CLOSED_AGAIN: if (now - startupVentTimer >= 1000) { ventServo.writeMicroseconds(SERVO_STOP_PULSE); ventState = VENT_CLOSED; startupVentDone = true; displayNeedsUpdate = true; } break;
    }
    yield();
    return;
  }

  unsigned long now = millis();

  // Fan RPM Calculation with Ghost RPM / Floating Line Cut-off
  if (now - lastRpmMs >= RPM_SAMPLE_MS) {
    if (fanDutyCycle == 0 || fanSpeed == FAN_OFF || digitalRead(FAN_POWER_PIN) == LOW) {
      currentFanRPM = 0.0f;
      noInterrupts();
      fanPulseCount = 0;
      interrupts();
    } else {
      noInterrupts();
      unsigned long p = fanPulseCount;
      fanPulseCount = 0;
      interrupts();
      unsigned long elapsedMs = now - lastRpmMs;
      currentFanRPM = (p > 0) ? (p * 60.0f * 1000.0f) / (elapsedMs * 2.0f) : 0.0f;
    }
    lastRpmMs = now;
    displayNeedsUpdate = true;
  }

  // Rotary Encoder Processing
  long c = encoder.getCount();
  if (c != lastEncoderCount) {
    long d = lastEncoderCount - c;
    lastEncoderCount = c;
    if (!inSubMenu) {
      menuIndex = (menuIndex + (int)d + MENU_LEN) % MENU_LEN;
      displayNeedsUpdate = true;
    } else if (activeMode == 5) {
      customTarget = constrain(customTarget + 0.5f * d, 0.0f, 120.0f);
      activeTarget = customTarget;
      customTargetDirty = true;
      lastCustomChangeMs = millis();
      displayNeedsUpdate = true;
    }
  }

  // Debounced NVS flush for custom target (protects flash wear)
  if (customTargetDirty && millis() - lastCustomChangeMs >= 2000) {
    prefs.putFloat("customTarget", customTarget);
    customTargetDirty = false;
  }

  // Rotary Encoder Button Click Processing
  static int lastBtn = HIGH;
  int btn = digitalRead(ENCODER_BTN);
  if (lastBtn == HIGH && btn == LOW && (millis() - lastBtnDebounceMs >= BTN_DEBOUNCE_MS)) {
    unsigned long btnNow = millis();
    lastBtnDebounceMs = btnNow;
    if (!inSubMenu && menuIndex != 7) {
      activeMode = menuIndex;
      activeTarget = (activeMode == 5) ? customTarget : menuTargets[activeMode];
      prefs.putInt("activeMode", activeMode);
      if (customTargetDirty) { prefs.putFloat("customTarget", customTarget); customTargetDirty = false; }
      inSubMenu = true;
      waitingForSecondSHOW = false;
      lastBtnPressMs = btnNow;

      if (!isnan(chamberTemp)) {
        if (chamberTemp > activeTarget + HYSTERESIS_TO_FULL) {
          startOpenVent(false);
          updateFan(FAN_HIGH);
        } else if (chamberTemp > activeTarget + HYSTERESIS_TO_HALF) {
          startOpenVent(true);
          updateFan(FAN_LOW);
        } else {
          updateFan(FAN_OFF);
        }
      } else {
        updateFan(FAN_OFF);
      }

      if (activeMode == 6) {
        cooldownStartMs = cooldownLastCheckMs = btnNow;
        cooldownStartTemp = isnan(chamberTemp) ? 60.0f : chamberTemp;
        cooldownLastTemp = cooldownStartTemp;
        cooldownFanDuty = NORMAL_MIN_DUTY;
        cooldownEstSeconds = -1;
        cooldownProgress = 0.0f;
        startOpenVent(false);  // Open vent first to avoid back-pressure
        setFanDuty(cooldownFanDuty, false); // Then engage fan at min 20%
      }
      displayNeedsUpdate = true;
    } else {
      if (waitingForSecondSHOW && btnNow - lastBtnPressMs <= DOUBLE_CLICK_MS) {
        inSubMenu = false;
        waitingForSecondSHOW = false;
        if (customTargetDirty) { prefs.putFloat("customTarget", customTarget); customTargetDirty = false; }
        updateFan(FAN_OFF);
        startCloseVent();
        displayNeedsUpdate = true;
      } else {
        waitingForSecondSHOW = true;
        lastBtnPressMs = btnNow;
      }
    }
  }
  lastBtn = btn;
  if (waitingForSecondSHOW && millis() - lastBtnPressMs > DOUBLE_CLICK_MS) waitingForSecondSHOW = false;

  // DHT11 Sensor Reading
  if (now - lastDhtReadMs >= DHT_MIN_INTERVAL_MS) {
    float t = dht.readTemperature();
    float h = dht.readHumidity();
    if (!isnan(t) && t > -40 && t < 80) {
      ambientTemp = t;
      ambientHum = isnan(h) ? NAN : roundf(h);
      displayNeedsUpdate = true;
    }
    lastDhtReadMs = now;
  }

  // Non-blocking OneWire DS18B20 Temp Conversion
  if (!tempsRequested && now - lastTempRequestMs >= 1000) requestTempsNonBlocking();
  else if (tempsRequested && now - lastTempRequestMs >= DS_CONV_MS) readTempsAfterDelay();

  // Mode & Thermal Control Routine
  if (inSubMenu && !isnan(chamberTemp)) {
    // Intake fault overrides everything
    if (!intakeFault && !isnan(intakeTemp) && intakeTemp > chamberTemp + 5.0f) {
      intakeFault = true;
      startOpenVent(false);
      updateFan(FAN_HIGH);
      displayNeedsUpdate = true;
    } else if (intakeFault && !isnan(intakeTemp) && intakeTemp <= chamberTemp + 2.0f) {
      intakeFault = false;
      displayNeedsUpdate = true;
    }

    if (intakeFault) {
      updateFan(FAN_HIGH);
      startOpenVent(false);
    } else if (activeMode == 6) {
      // COOLDOWN MODE
      float target = isnan(ambientTemp) ? 25.0f : ambientTemp + COOLDOWN_TARGET_OFFSET;
      bool cooldownFinished = (chamberTemp <= target + 0.5f);

      if (cooldownLastCheckMs == 0 || isnan(cooldownLastTemp)) {
        cooldownLastCheckMs = now;
        cooldownLastTemp = chamberTemp;
      }

      // Keep vent open during active cooling
      if (!cooldownFinished && ventState != VENT_OPEN && ventState != VENT_OPENING) {
        startOpenVent(false);
      }

      // Smooth 1-second countdown tick for remaining time estimate
      if (cooldownEstSeconds > 0 && now - lastCountdownSecMs >= 1000) {
        cooldownEstSeconds--;
        lastCountdownSecMs = now;
        displayNeedsUpdate = true;
      }

      // 60-second adaptive rate adjustment sample window
      if (now - cooldownLastCheckMs >= COOLDOWN_SAMPLE_MS) {
        float drop = cooldownLastTemp - chamberTemp;

        if (cooldownFinished) {
          setFanDuty(0, true); // Hard kill fan
          startCloseVent();
          cooldownEstSeconds = 0;
          cooldownProgress = 1.0f;
          displayNeedsUpdate = true;
        } else {
          float dpm = drop * (60000.0f / (now - cooldownLastCheckMs));
          int8_t adj = (dpm < COOLDOWN_RATE_DEG_PER_MIN - 0.3f) ? 20 :
                       (dpm > COOLDOWN_RATE_DEG_PER_MIN + 0.3f) ? -20 : 0;
          
          // Enforce minimum 20% fan duty (NORMAL_MIN_DUTY) while cooling active
          cooldownFanDuty = constrain(cooldownFanDuty + adj, NORMAL_MIN_DUTY, 255);
          setFanDuty(cooldownFanDuty, false);

          float total = cooldownStartTemp - target;
          float currentDrop = cooldownStartTemp - chamberTemp;
          cooldownProgress = (total > 0.5f) ? constrain(currentDrop / total, 0.0f, 1.0f) : 1.0f;

          if (drop > 0.1f && total > 0.5f && (now - cooldownLastCheckMs) > 1000) {
            float rate = drop * (60000.0f / (now - cooldownLastCheckMs));
            if (rate > 0.1f) {
              float rem = chamberTemp - target;
              if (rem > 0) {
                cooldownEstSeconds = (long)(rem / rate * 60.0f);
                lastCountdownSecMs = now;
              }
            }
          }
        }
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

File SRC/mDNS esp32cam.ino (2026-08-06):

/*  ESP32-CAM 3D Printer Live Cam – FINAL CLEAN & WORKING  */
#include "esp_camera.h"
#include <WiFi.h>
#include <ESPmDNS.h>
#include "img_converters.h"
#include "esp_http_server.h"

// ---------- PINS ----------
#define PWDN_GPIO_NUM     32
#define RESET_GPIO_NUM    -1
#define XCLK_GPIO_NUM      0
#define SIOD_GPIO_NUM     26
#define SIOC_GPIO_NUM     27
#define Y9_GPIO_NUM       35
#define Y8_GPIO_NUM       34
#define Y7_GPIO_NUM       39
#define Y6_GPIO_NUM       36
#define Y5_GPIO_NUM       21
#define Y4_GPIO_NUM       19
#define Y3_GPIO_NUM       18
#define Y2_GPIO_NUM        5
#define VSYNC_GPIO_NUM    25
#define HREF_GPIO_NUM     23
#define PCLK_GPIO_NUM     22
#define FLASH_LED_PIN      4

// ---------- WIFI ----------
const char* ssid = "*********";
const char* password = "*********";

// ---------- GLOBALS ----------
httpd_handle_t stream_httpd = NULL;
httpd_handle_t camera_httpd = NULL;
bool flashOn = false;
unsigned long flashOnTime = 0;
const unsigned long FLASH_TIMEOUT = 4UL * 60UL * 1000UL;  // 4 minutes

// ---------- HTML ----------
static const char PROGMEM INDEX_HTML[] = R"rawliteral(
<!DOCTYPE html><html><head><meta charset="utf-8"><title>3D Print LIVE</title>
<style>
  body{background:#111;color:#fff;font-family:Arial;text-align:center;margin:0;padding:20px;}
  button,select{padding:10px 16px;margin:6px;border:none;border-radius:8px;background:#444;color:#fff;cursor:pointer;font-size:16px;}
  button:hover,select:hover{background:#666;}
  .stream-container{width:1280px;height:1024px;max-width:98vw;margin:10px auto;background:#000;border-radius:10px;overflow:hidden;}
  #stream{width:100%;height:100%;object-fit:contain;}
  #snapshot{display:none;margin-top:20px;max-width:98vw;border-radius:10px;}
</style></head><body>
<h2>3D Printer LIVE Feed</h2>
<div class="stream-container"><img id="stream" src=""></div><br>
<select id="framesize" onchange="set('framesize',this.value)">
  <option value="9" selected>SXGA (1280x1024)</option>
  <option value="8">XGA (1024x768)</option>
  <option value="7">SVGA (800x600)</option>
  <option value="6">VGA (640x480)</option>
</select>
<select id="jpegquality" onchange="set('jpegquality',this.value)">
  <option value="5">High (5)</option>
  <option value="8" selected>Good (8)</option>
  <option value="12">Medium (12)</option>
  <option value="15">Fast (15)</option>
</select><br>
<button onclick="snap()">Snapshot</button>
<button id="flashBtn" onclick="toggleFlash()">Flash: OFF</button><br>
<img id="snapshot" src="">
<script>
const ip=location.hostname;
document.getElementById('stream').src=`http://${ip}:81/stream?t=${Date.now()}`;
const sizes={'9':{w:1280,h:1024},'8':{w:1024,h:768},'7':{w:800,h:600},'6':{w:640,h:480}};
let blobUrl=null;
async function snap(){
  document.getElementById('snapshot').style.display='none';
 const b=await (await fetch(`/capture?t=${Date.now()}`,{cache:'no-store'})).blob();
 if(blobUrl)URL.revokeObjectURL(blobUrl);
 blobUrl=URL.createObjectURL(b);
 document.getElementById('snapshot').src=blobUrl;
 document.getElementById('snapshot').style.display='block';
}
async function toggleFlash(){
 const on=(await (await fetch('/flash')).text()).trim()==='ON';
 document.getElementById('flashBtn').innerText='Flash: '+(on?'ON':'OFF');
}
function set(p,v){
 fetch(`/control?var=${p}&val=${v}`);
 if(p==='framesize'){
  const s=sizes[v];
  document.querySelector('.stream-container').style.width=s.w+'px';
  document.querySelector('.stream-container').style.height=s.h+'px';
  document.getElementById('stream').src=`http://${ip}:81/stream?t=${Date.now()}`;
 }
 if(p==='jpegquality') document.getElementById('stream').src=`http://${ip}:81/stream?t=${Date.now()}`;
}
// NO auto toggleFlash() here → flash stays OFF on page load
</script></body></html>
)rawliteral";

// ---------- HANDLERS ----------
static esp_err_t stream_handler(httpd_req_t *req){
  camera_fb_t *fb = NULL;
  esp_err_t res = ESP_OK;
  size_t jpg_len = 0;
  uint8_t *jpg_buf = NULL;
  char part_buf[128];

  httpd_resp_set_type(req, "multipart/x-mixed-replace;boundary=frame");
  httpd_resp_set_hdr(req, "Access-Control-Allow-Origin", "*");

  while(true){
    fb = esp_camera_fb_get();
    if(!fb){ delay(10); continue; }

    if(fb->format != PIXFORMAT_JPEG){
      frame2jpg(fb, 80, &jpg_buf, &jpg_len);
      esp_camera_fb_return(fb);
    } else {
      jpg_len = fb->len;
      jpg_buf = fb->buf;
    }

    snprintf(part_buf, sizeof(part_buf), "\r\n--frame\r\nContent-Type: image/jpeg\r\nContent-Length: %u\r\n\r\n", (unsigned int)jpg_len);
    httpd_resp_send_chunk(req, part_buf, strlen(part_buf));
    res = httpd_resp_send_chunk(req, (const char*)jpg_buf, jpg_len);

    if(fb->format != PIXFORMAT_JPEG) free(jpg_buf);
    esp_camera_fb_return(fb);
    if(res != ESP_OK) break;
  }
  return res;
}

static esp_err_t capture_handler(httpd_req_t *req){
  camera_fb_t *fb = esp_camera_fb_get();
  if(!fb){ httpd_resp_send_500(req); return ESP_FAIL; }
  httpd_resp_set_type(req, "image/jpeg");
  httpd_resp_send(req, (const char*)fb->buf, fb->len);
  esp_camera_fb_return(fb);
  return ESP_OK;
}

static esp_err_t flash_handler(httpd_req_t *req){
  flashOn = !flashOn;
  digitalWrite(FLASH_LED_PIN, flashOn ? HIGH : LOW);
  if(flashOn) flashOnTime = millis();
  httpd_resp_send(req, flashOn ? "ON" : "OFF", -1);
  return ESP_OK;
}

static esp_err_t cmd_handler(httpd_req_t *req){
  char var[32]={}, val[32]={};
  size_t len = httpd_req_get_url_query_len(req) + 1;
  if(len > 1){
    char* buf = (char*)malloc(len);
    if(buf){
      httpd_req_get_url_query_str(req, buf, len);
      if(httpd_query_key_value(buf,"var",var,sizeof(var))==ESP_OK &&
         httpd_query_key_value(buf,"val",val,sizeof(val))==ESP_OK){
        int v = atoi(val);
        sensor_t *s = esp_camera_sensor_get();
        if(strcmp(var,"framesize")==0) s->set_framesize(s, (framesize_t)v);
        else if(strcmp(var,"jpegquality")==0) s->set_quality(s, v);
      }
      free(buf);
    }
  }
  httpd_resp_send(req, "OK", 2);
  return ESP_OK;
}

static esp_err_t index_handler(httpd_req_t *req){
  httpd_resp_set_type(req, "text/html");
  return httpd_resp_send(req, INDEX_HTML, strlen(INDEX_HTML));
}
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

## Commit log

2026-08-06 Release v2.5: Multi-file modular architecture & production enhancements
    [Dshaft 6mm knob.3mf, Dshaft 6mm knob.prt, XM4015E1 footprint.prt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]
2026-08-06 Update product title to Chamber Master
2026-08-06 Fix stale v2.4 debug string to Chamber Master v2.5
    [Chamber-Master.ino, Rev.2.5.ino]
2026-08-06 Streamline codebase layout for Arduino IDE
2026-08-06 Fix Arduino IDE compilation error by removing leftover modular .cpp files from SRC folder
2026-08-08 Fix fan hard kill desync bug (ensure transistor cuts GND when OFF in all modes)
    [Chamber-Master.ino, Rev.2.5.ino]
2026-08-08 v2.6: Fix fan hard kill desync + recalibrate hysteresis thresholds (fan was engaging 1C below target)
    [Rev.2.6.ino]
2026-08-08 Fix fan slow spinning via 25kHz Intel PWM spec + High-Z pin isolation for parasitic grounding
    [Chamber-Master.ino, Rev.2.6.ino]
2026-08-09 v2.7: True 0-RPM Parasitic Grounding Kill via High-Z pin isolation on PWM and Tach pins
2026-08-09 v2.8: Drive GPIO 33 HIGH (3.3V) on FAN_OFF to eliminate voltage potential across inline diodes and PWM line
2026-08-09 Fix RPM always showing zero: track fan power state to prevent constant interrupt re-attachment
    [Chamber-Master.ino, Rev.2.8.ino]
2026-09-05 v2.9-beta: Klipper integration with /material REST endpoint
    Features & Enhancements:
    - Added /material endpoint supporting both HTTP GET and POST requests with CORS headers (Access-Control-Allow-Origin: *).
    - Implemented case-insensitive parsing for material presets (PLA, ASA, ABS, TPU, PETG), CUSTOM mode, and COOLDOWN.
    - Added float-precision target temperature setting (0.0C to 120.0C) for CUSTOM mode with non-volatile storage (NVS) persistence.
    - Added internal state synchronization (inSubMenu = true, menuIndex sync) and immediate directional hysteresis evaluation for instant vent and fan reaction.
    - Documented full Klipper macro configuration (SET_CHAMBER_MATERIAL, START_CHAMBER_COOLDOWN)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
2026-09-19 Add tested Klipper integration script and macros (Issue #3)
    - Added Klipper/chamber_trigger.sh with IPv4 ping caching to eliminate mDNS resolution lag in Klipper subshells.
    - Added Klipper/chamber_master.cfg with tested macros (Chamber_Master, chamber_curl using $HOME/chamber_trigger.sh, SET_CHAMBER, START_CHAMBER_COOLDOWN).
    - Added Klipper/README.md with setup instructions and slicer examples.
    - Updated root README.md and product.md to reflect the verified hardware test by @richard-kennett (Issue #3, comment 5619889047).
    [chamber_master.cfg]
